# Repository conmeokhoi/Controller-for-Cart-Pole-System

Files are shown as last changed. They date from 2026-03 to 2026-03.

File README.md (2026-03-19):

# 150W Isolated Cart-Pole Control Board (STM32)





## 📌 Project Overview
This project presents the design and implementation of a specialized control board for an Inverted Pendulum on a Cart (Cart-Pole) system. It serves as a benchmark for testing cascaded control strategies in highly non-linear, unstable, and under-actuated environments.

## 🛠 Hardware Architecture

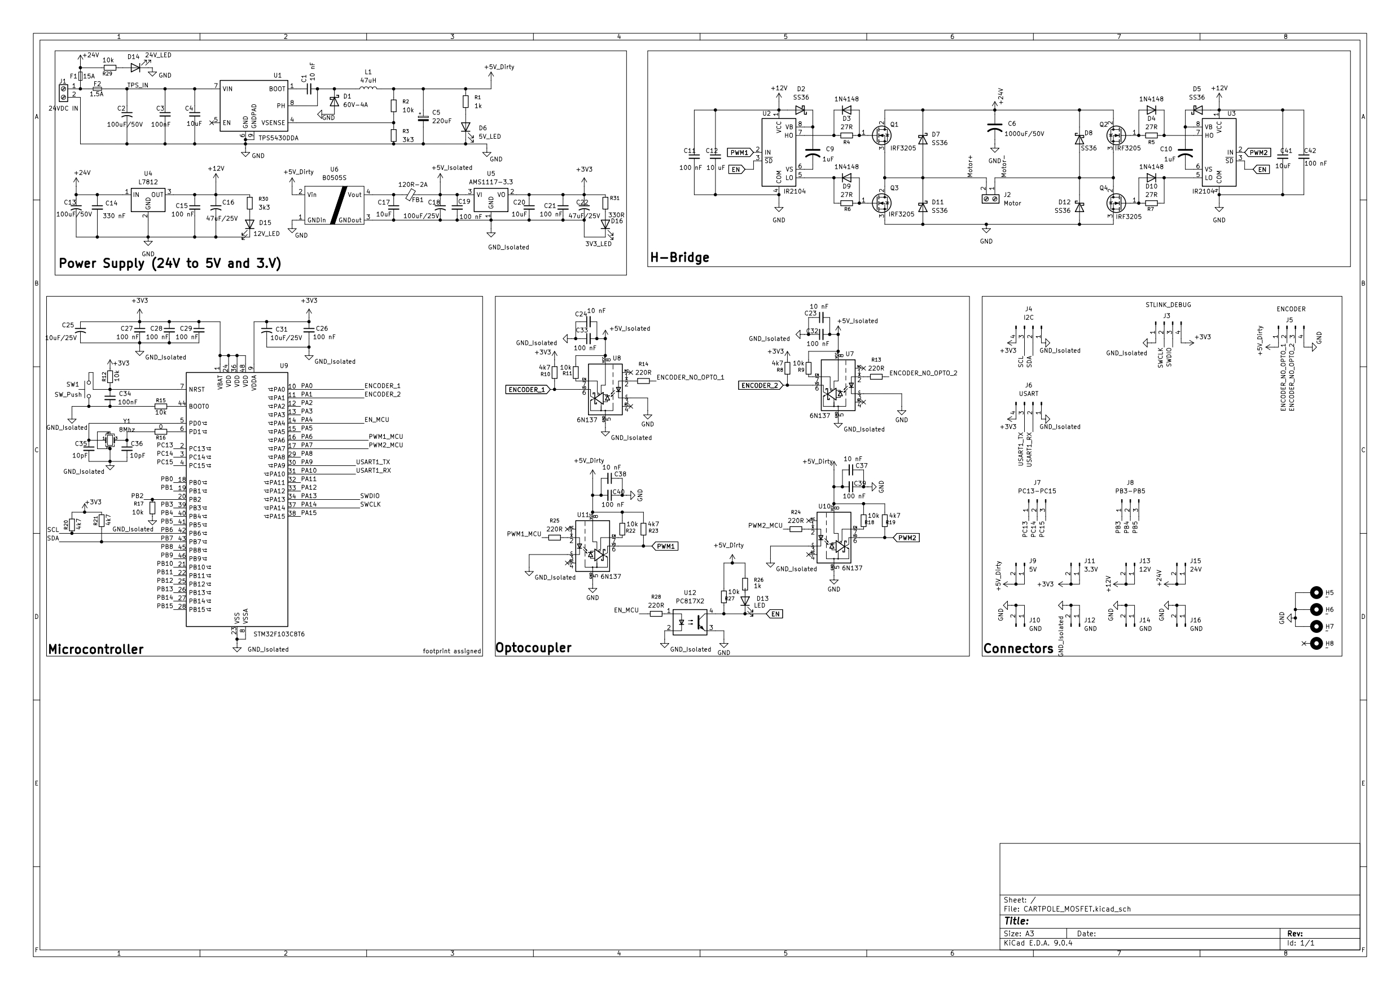
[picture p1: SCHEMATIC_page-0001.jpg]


### 1. Multi-Stage Power Management
The system operates on a primary **24V DC** input with hierarchical regulation to ensure signal stability and efficiency:
* **12V Rail**: Regulated by the **L7812** for MOSFET gate drivers.
* **5V Auxiliary Rail**: Stepped down via a high-efficiency **TPS5430 Buck Converter** (~90% efficiency) to power encoders and sensors.
* **Isolated 3.3V Logic**: Utilizes a **B0505S** isolated DC-DC converter and an **AMS1117-3.3** LDO to shield the MCU from power-stage inductive switching noise.

### 2. Motor Drive Stage (150W H-Bridge)
* **MOSFET Selection**: Features four **IRF3205S** N-channel MOSFETs with an exceptionally low $R_{DS(on)} \approx 8 m\Omega$ to minimize conduction losses.
* **Gate Driving**: Employs **IR2104** drivers with bootstrap circuitry to maintain high-side gate saturation.
* **Safety Logic**: Integrated **520ns hardware dead-time** prevents "shoot-through" short circuits.

### 3. Galvanic Isolation
* **High-Speed Paths**: **6N137 optocouplers** (10Mbps) are dedicated to PWM and Encoder signals to prevent propagation delay in the real-time control loop.
* **Isolation Barrier**: Complete physical partitioning between the Power Zone and Clean Logic Zone via the optocoupler bridge.
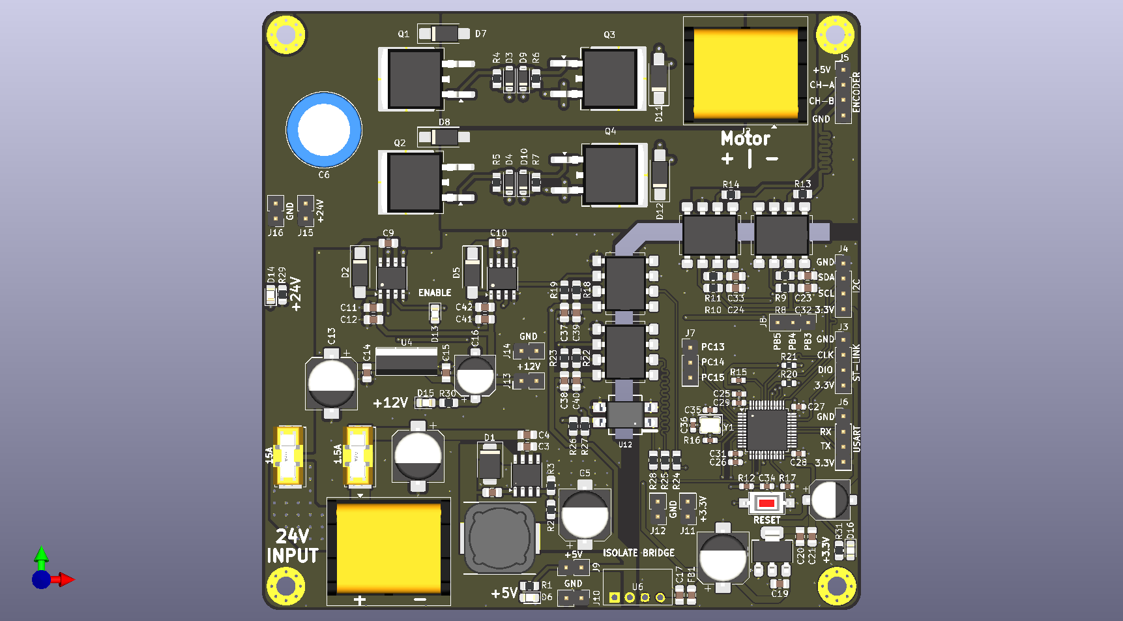
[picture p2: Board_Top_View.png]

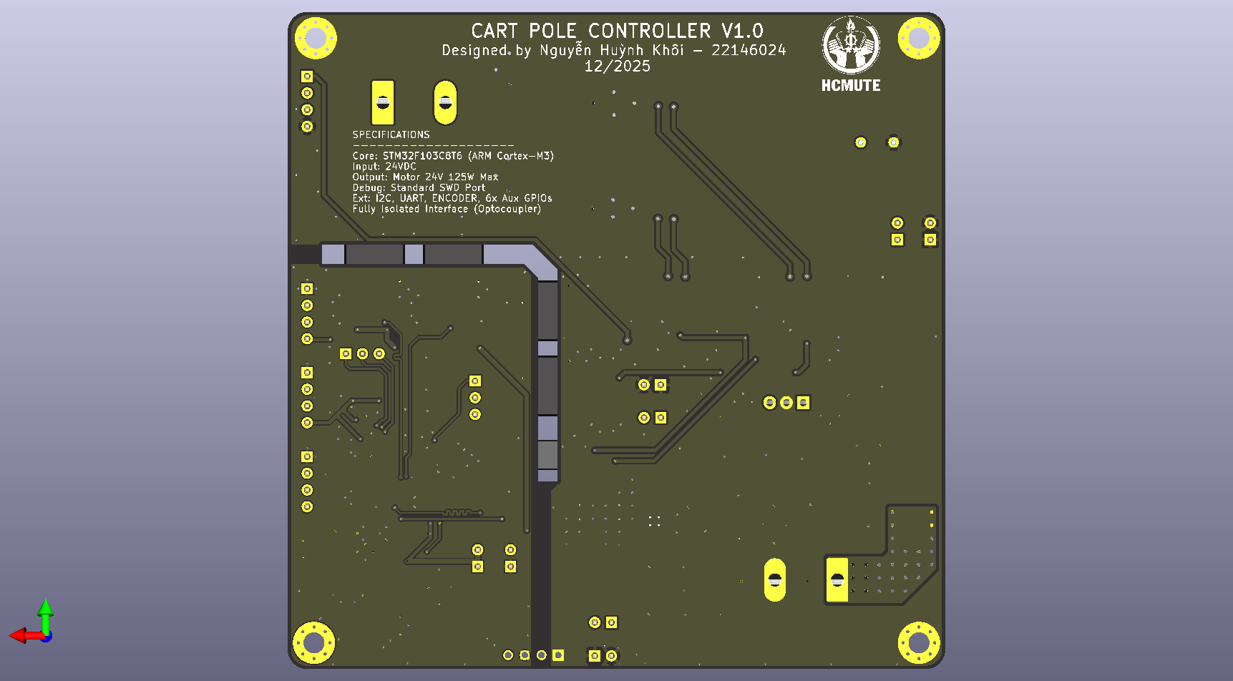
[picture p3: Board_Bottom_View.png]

## 💻 Firmware & Control Logic
Powered by the **STM32F103C8T6** (ARM Cortex-M3) at **72MHz**:
* **Encoder Processing**: Utilizes hardware Timer Encoder Mode for high-resolution quadrature decoding without CPU overhead.
* **PWM Configuration**: Frequency set at **20kHz** to eliminate audible jitter and provide granular torque control:
  $$f_{PWM} = \frac{f_{CLK}}{(PSC+1) \times (ARR+1)} = \frac{72,000,000}{36 \times 100} = 20,000 \text{ Hz}$$
* **Control Algorithm**: Implements a **Cascaded PID** structure where the outer loop manages cart position and the inner loop stabilizes the pendulum angle.

## 🔍 Failure Analysis (Root Cause)
During integration, a hardware breakdown occurred in the H-bridge. Forensic analysis identified a missing connection between the **VS pin** (Pin 6) of the IR2104 drivers and the **source terminals** of the high-side MOSFETs.This led to a "floating gate" state, causing a direct short-circuit from the 24V rail to Ground.

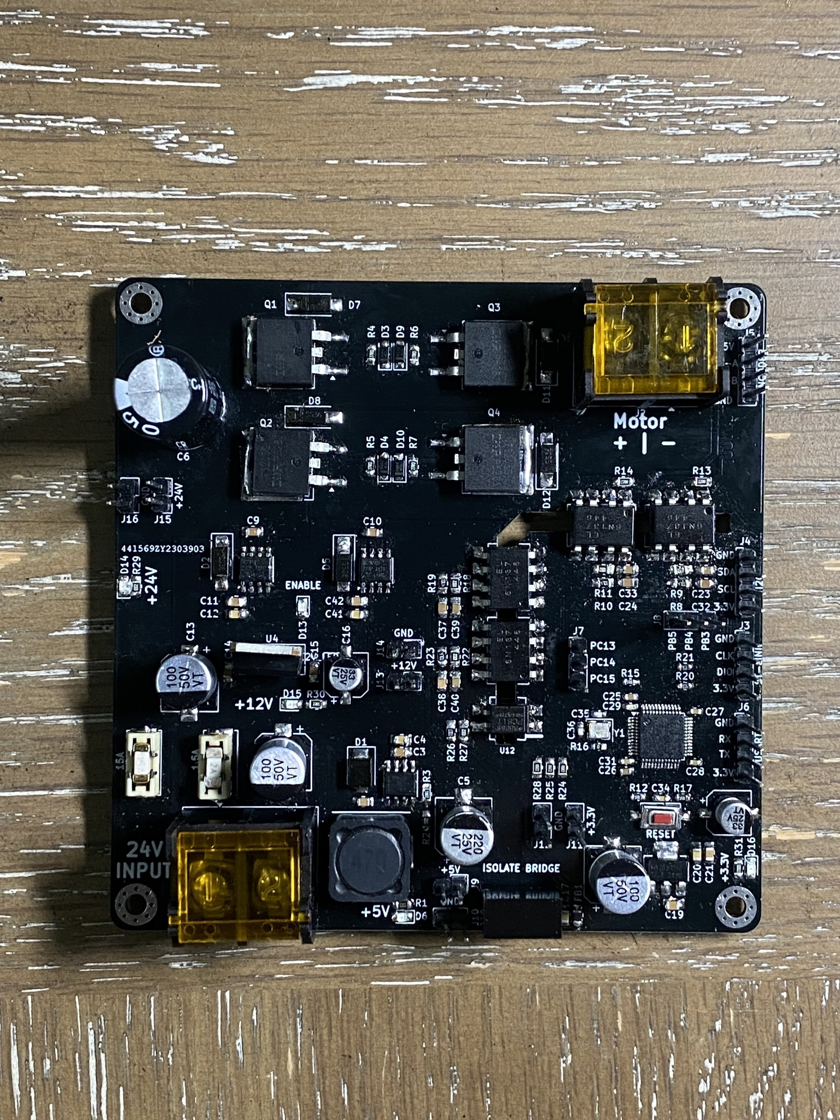
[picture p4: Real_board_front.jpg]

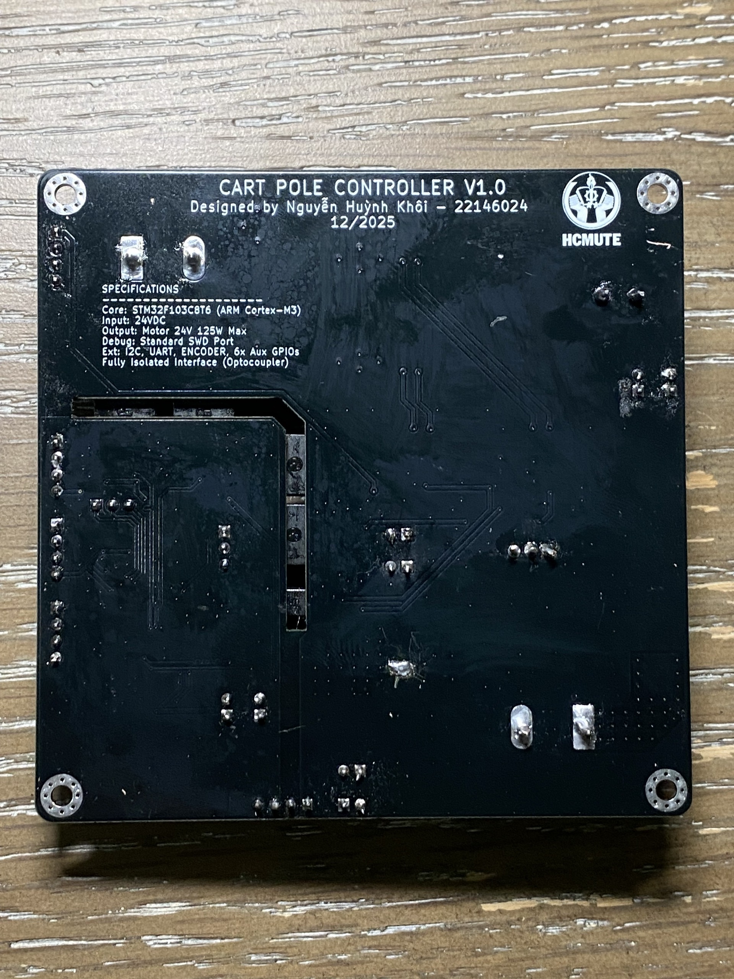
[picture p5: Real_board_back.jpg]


## 🎥 Experimental Validation
The following video demonstrates the individual functional verification of the control board:
* **Hardware Self-Test:** Verification of the 24V, 12V, 5V, and 3.3V power rails.
* **Encoder & Sensor Feedback:** Real-time pulse capturing and gyroscope data retrieval.
* **PWM Output:** Validation of 20kHz complementary signals via oscilloscope.
* **Video Demo:** Cart-Pole Demo (https://youtu.be/A-W4OBMFTu4?si=EoCC8th8CacCnSwT)

---
**Author**: Nguyễn Huỳnh Khôi.  
**Supervised by**: PhD. Võ Lâm Chương.   
**University**: Ho Chi Minh City University of Technology and Engineering (HCMUTE)

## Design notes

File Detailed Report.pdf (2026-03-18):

HO CHI MINH CITY UNIVERSITY OF TECHNOLOGY AND ENGINEERING FACULTY OF ADVANCED EDUCATION

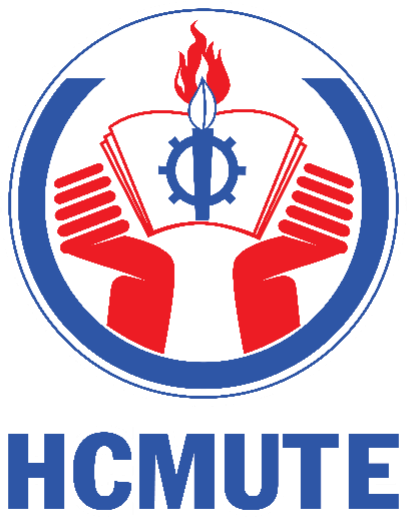
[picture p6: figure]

# DESIGN OF A CONTROL INTERFACE BOARD FOR THE CART-POLE SYSTEM

### Supervisor: PhD. Võ Lâm Chương

### Student: Nguyễn Huỳnh Khôi - ID: 22146024

### Course: Project of Mechatronic System

### Course ID: 251PRME315129E_07FIE

### Semester: I – Academic year: 2025-2026

### Ho Chi Minh City, January, 2026

ACKNOWLDGEMENTS

I would like to extend my deepest and most sincere gratitude to my supervisor,

PhD. Võ Lâm Chương, for his profound guidance, unwavering support, and invaluable

mentorship throughout the entire journey of this project. This research, centered on the

design and implementation of a control interface board for the Cart-Pole system,

presented numerous technical hurdles that would have been insurmountable without his

expertise. While this is not my first experience in designing a Printed Circuit Board, this

project involved the most detailed and complexity layout I have ever attempted. Under

his supervision, I understand the important of the deep research before doing anything

and a lot of precious things. The lessons learned during this process have provided me

with priceless knowledge that will undoubtedly strengthen my professional path and

serve as a cornerstone for my future career as an engineer.

I am also deeply appreciative of the Ho Chi Minh City University of Technology

and Enginnering and the esteemed professors within the Faculty of Mechanical

Engineering. The useful knowledge and robust skills I have acquired through years of

lectures and practical training were essential in allowing me to successfully complete

this Project in Mechatronics. I feel honored to have been part of a faculty that fosters

such a high standard of excellence and innovation.

In the pursuit of engineering, I recognize that mistakes are often unavoidable, yet

they serve as the most profound teachers. Throughout this project, I have exerted my

maximum effort to apply the theoretical concepts I have learned to a physical, working

model. This experience has humbled me and reinforced the realization that knowledge

is infinite. I am fully aware of my current limitations and remain deeply committed to

the philosophy of lifelong learning. Therefore, I sincerely hope to receive constructive

criticism and feedback regarding this work. I welcome every critique as an opportunity

to improve myself, refine my skills, and expand the boundaries of my limited

knowledge. I am truly grateful for the opportunity to have conducted this research, and

I look forward to applying the strengths I have gained here to make meaningful

contributions to the field of engineering in the years to come.

FEEDBACK OF SUPERVISOR

Ho Chi Minh City, January, 2026

Supervisor

TABLE OF CONTENTS

ACKNOWLDGEMENTS | 0
FEEDBACK OF SUPERVISOR | 1
TABLE OF CONTENTS | 2
CHAPTER I: INTRODUCTION | 1
1.1. Background and Motivation | 1
1.2. Objectives of the Thesis | 1
1.3. Scope and Limitation | 2
1.4. Research Methodology | 2
1.5. Thesis Structure | 3
CHAPTER II: THEORETICAL BACKGROUND | 4
2.1. Mathematical Modeling of the Cart-Pole System | 4
2.1.1. System Parameters and Coordinates | 4
2.1.2. Energy Analysis | 5
2.1.3. Euler-Lagrange Equations | 5
2.1.4. Linearization | 6
2.2. PID Control Theory | 6
2.2.1. Individual Control Components | 7
2.2.2. Impact on System Response | 7
2.3. Cascaded PID Control Structure | 8
2.3.1. The Necessity of Dual Control Loops | 8
2.3.2. Operating Principle and Interaction | 8
2.3.3. Sampling Frequency and Stability | 9
2.4. Power Electronics and Motor Driving | 9
2.4.1. H-Bridge and MOSFET Switching | 9
2.4.2. Pulse Width Modulation (PWM) | 10

4.2.3. Timer Interrupt (10ms Periodic Task) | 32
4.3. Controller Programming | 33
CHAPTER V: RESULTS AND EVALUATION | 34
5.1. Hardware Assembly and Power-on Self-Test | 34
5.2. Individual Functional Verification | 34
5.3. Technical Challenges and Failure Analysis | 35
5.3.1. Incident Description | 35
5.3.2. Root Cause Analysis | 36
CHAPTER VI: CONCLUSION | 37
6.1. Conclusion | 37
6.2. Future Work | 37
CITIATION | 38

LIST OF FIGURES

Figure 1.1: Diagram of inverted pendulum on a cart | 4
Figure 2.1: PID Block Diagram | 6
Figure 2.2: Cascade PID System | 8
Figure 2.3: Typical MOSFET H-Bridge configuration | 10
Figure 2.4: PWM & Duty Cycle | 10
Figure 2.5: Linear Voltage Regulator | 11
Figure 2.6: Buck Converter | 12
Figure 2.7: Quadrature Encoder principle | 13
Figure 2.8: Inside of Optocoupler | 13
Figure 3.1: Hardware Architecture for Cart Pole System | 14
Figure 3.2: LM7812 Diagram | 15
Figure 3.3: TPS5430DDAR schematic diagram | 16
Figure 3.4: B0505S Isolation Bridge | 17

Figure 3.5.6: The physical layout of the control board, highlighted the strategic

CHAPTER I: INTRODUCTION

### 1.1. Background and Motivation

The Cart-Pole system, also known as the Inverted Pendulum on a Cart, is one of the

most fundamental and classic problems in control theory and robotics. It serves as a

benchmark for testing various control strategies due to its specific characteristics: it is

highly non-linear, unstable and under-actuated. The challenge of balancing a pole

vertically by moving a cart horizontally mimics real-world applications such as the

stabilization of space booster rockets during takeoff, the balance of humanoid robots,

and the operation of self-balancing personal transporters like Segways. However,

transitioning from theoretical simulations to physical hardware presents several

engineering challenges. Generic development boards (such as STM32 Blue Pill or

Arduino UNO) often lack the specialized interfaces for electrical isolation, power

management, signal integrity and interfacing. Therefore, designing a dedicated control

interface board is essential to ensure system stability, safety, and performance. This

project not only serves as a practical academic exercise but also provides a foundation

for mastering real-time embedded control and high-performance electronic design.

### 1.2. Objectives of the Thesis

The primary objective of this project is to design and manufacture a high-

performance control interface board based on the STM32 microcontroller, focusing on

high-power efficiency and signal integrity. Specifically, the board features a custom

H-Bridge MOSFET driver capable of handling a maximum power output of 150W for

robust DC motor control. The power management system is designed to accept a 24V

DC input and provide multiple regulated voltage levels, including 12V for gate driving

and 5V/3.3V for logic and supply for microcontroller. For feedback accuracy and system

protection, the board integrates high speed – optocoupler isolated for encoder interfaces

and PWM outputs to prevent electromagnetic interference and back-EMF from affecting

the microcontroller. Furthermore, it intergrated standard communication protocols such

as I2C for peripheral sensor and USART for data logging and debugging, while utilizing

high-frequency PWM outputs for smooth and precise motor actuation.

### 1.3. Scope and Limitation

This project focuses on the design and implementation of a custom-built hardware

control system specifically for a linear Cart-Pole system, utilizing the STM32

microcontroller as the primary processing unit. The hardware scope is confined to the

development of a dedicated Printed Circuit Board (PCB) that integrates a MOSFET-

based H-Bridge driver with a power rating of 150W, although the design considerations

allow for higher peaks provided if thermal management is maintained. The system is

designed around a primary 24V DC input, employing a multi-stage regulation strategy

to balance efficiency and signal stability. A linear regulator is utilized to step down 24V

to a 12V rail dedicated to the MOSFET gate drivers; a linear topology is chosen here

due to the low current demand of gate driving, which minimizes circuit complexity. In

contrast, to the voltage differential between the 24V input and the 5V logic level, a high-

efficiency buck converter is implemented. This switching regulator minimizes thermal

dissipation while providing a robust 5V supply for power-intensive peripherals,

including the quadrature encoders and communication interfaces such as I2C and

USART. Finally, the 5V rail is further regulated down to 3.3V to ensure a stable and

low-noise operating voltage for the STM32 microcontroller’s core logic. From a control

perspective, the project implements a Cascaded PID algorithm tailored to the linearized

dynamics of the pendulum near its vertical equilibrium, excluding advanced non-linear

or heuristic control methods.

### 1.4. Research Methodology

This project follows a structured engineering approach consisting of four key

phases: Fristly is Theoretical Modeling by analyzing system dynamics to establish a

linearized mathematical model for PID control design. Next is Hardware Engineering

by designing a high-power PCB that integrates an STM32 Microcontroller, a 150W

MOSFET H-Bridge, and isolated sensor interfaces with a multi-stage power

management system. After that, Software Development by implementing real-time C-

based algorithms on the STM32 platform, leveraging hardware timers for precise PWM

generation and encoder decoding. Finally Experimental Validation by Conducting

physical tests to evaluate system stability and iteratively tuning PID parameters for

optimal balancing performance.

### 1.5. Thesis Structure

- Chapter 1: Introduction - Presents the background, research motivation, technical

objectives, and the overall methodology of the project.

- Chapter 2: Theoretical Background - Discusses the mathematical modeling of the

Cart-Pole system through physics-based equations and explores the theoretical

principles of Cascaded PID control.

- Chapter 3: Hardware Design - Details the design of the control interface board,

including component selection for the 150W MOSFET H-Bridge, the multi-stage power

system, and the PCB layout strategies for signal integrity and thermal management.

- Chapter 4: Software Development - Describes the software architecture on the

STM32 platform, focusing on real-time interrupt handling, hardware-level encoder

decoding, and the implementation of the control algorithms in C language.

- Chapter 5: Results And Evaluation - Details the testing procedures, PID tuning

process, and system performance analysis through real-time data graphs. This chapter

also evaluates the hardware's thermal stability and power handling capabilities under

operational loads.

- Chapter 6: Conclusion – Summarizes the project's outcomes in relation to the

initial objectives, acknowledges technical limitations encountered during development,

and proposes directions for future enhancements and research.

CHAPTER II: THEORETICAL BACKGROUND

### 2.1. Mathematical Modeling of the Cart-Pole System

The foundation of any control system is an accurate mathematical representation

of the physical plant. For the Cart-Pole system, modeling allows us to predict how the

cart's horizontal movement affects the pole's vertical stability. At the undergraduate

level, the Euler-Lagrange method is the most structured approach to deriving these

equations, as it focuses on the energy states of the system rather than complex vector

force diagrams.

### 2.1.1. System Parameters and Coordinates

To begin the analysis, we define the following physical constants and variables:

- M: Mass of the cart.
- m: Mass of the pole.
- l: Length from the pivot to the pole's center of mass.
- I: Moment of inertia of the pole (I =

1
3

ml

2
for a uniform rod).
- g: Acceleration due to gravity (9.81 m/s

2
).
- F: Force applied to the cart (the control input).
- x: Horizontal position of the cart.
- θ: Angle of the pole relative to the vertical (upright) position.

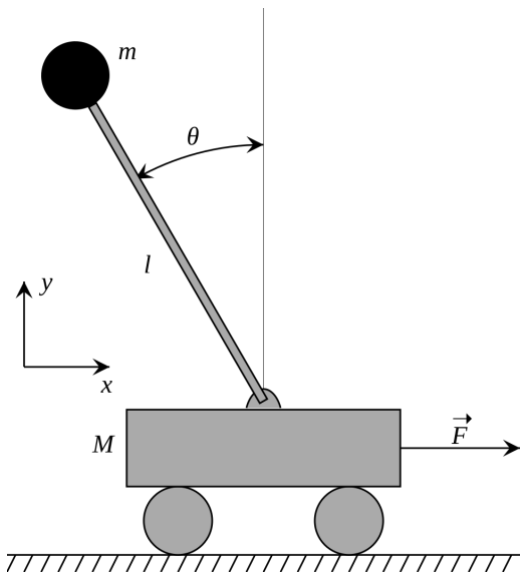
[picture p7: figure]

Figure 1.1: Diagram of inverted pendulum on a cart

The coordinates of the pole's center of mass (xp, yp) are expressed as:

xp = x + lsinθ

yp = lcosθ

### 2.1.2. Energy Analysis

The Lagrangian L is defined as the difference between the Total Kinetic

Energy (K) and the Total Potential Energy (V). Total Kinetic Energy is the energy

consists of the cart's translation and the pole's translation/rotation:

K =

1
2

Mẋ

2 +

1
2

m(xṗ

2 + yṗ

2
) +

1
2

Iθ̇²

By differentiating the coordinates (xp, yp) and substituting them into the

equation, we obtain:

K =

1
2

(M + m)ẋ

2 + mlẋθ̇cosθ +

1
2

(I + ml

2

)θ̇²

Total Potential Energy: Assuming the ground level as the zero-potential

reference:

V = mglcosθ

### 2.1.3. Euler-Lagrange Equations

The equations of motion are derived using the Euler-Lagrange formula for each

generalized coordinate qi

(where q1 = x and q2 = θ):

d
dt (

∂L
∂qi

̇

) −

∂L
∂qi

= Qi

Applying this to the system (where Qx = F and Qθ = 0) results in two coupled,

non-linear differential equations:

(M + m)ẍ+ mlθ̈cosθ − mlθ̇² sinθ = F

(I + ml

2

)θ̈+ mlẍcosθ − mglsinθ = 0

### 2.1.4. Linearization

Because standard PID controllers are linear, we must linearize the system around

the unstable equilibrium point (upright position, θ ≈ 0). For small angles, we can

assume:

- sinθ ≈ 0
- cosθ ≈ 1
- θ̇² ≈ 0 (negligible higher-order terms)

The linearized equations of motion become:

(M + m)ẍ+ mlθ̈= F

(I + ml

2

)θ̈+ mlẍ= mglθ

These equations represent the "transfer function" that controller board will eventually control through the PID algorithm.

### 2.2. PID Control Theory

The PID controller operates by continuously calculating an "error" value as the

difference between a desired setpoint and a measured process variable. For the

Cart-Pole system, this error represents how far the pole is from the vertical position or

how far the cart is from its target on the track.

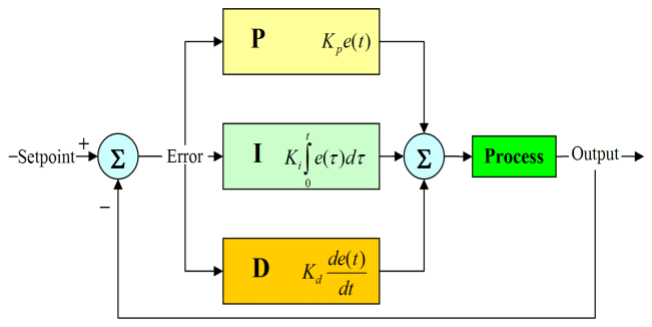
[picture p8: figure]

Figure 2.1: PID Block Diagram

### 2.2.1. Individual Control Components

The standard continuous-time PID control law is defined by the following

equation:

u(t) = Kpe(t) + Ki ∫ e(τ)dτ

t

0

+ Kd

de(t)
dt

Where:

- u(t): The control output
- e(t): The error signal, calculated as Setpoint – Measured Value
- Kp (Proportional Gain): Provides a control output that is directly proportional to

the current error. In the Cart-Pole system, a higher Kp makes the motor react more

aggressively as the pole tilts. However, if Kp is too high, the system will

overshoot the setpoint and oscillate.

- Ki
(Integral Gain): Accounts for the accumulation of past errors. If the error

persists over time, the integral term increases the control effort to eliminate the

offset.

- Kd (Derivative Gain): Estimates the future trend of the error based on its current

rate of change. It acts as a "damper" or a brake. If the pole is falling rapidly, the

derivative term anticipates the impact and applies a counter-force to slow down

the motion before it reaches the setpoint. This is critical for the Cart-Pole system

to prevent the violent oscillations caused by the Kp and Ki
terms.

### 2.2.2. Impact on System Response

When tuning term Kp,Ki or Kd the interaction between these terms determines

the stability of the cart. The following table summarizes the general effects of increasing

each parameter on the system's step response:

Parameter | Rise Time | Overshoot | Settling Time | Steady-State Error
Increasing Kp | Decrease | Increase | Small Change | Decrease
Increasing Ki | Decrease | Increase | Increase | Eliminate
Increasing Kd | Small Change | Decrease | Decrease | No Change

### 2.3. Cascaded PID Control Structure

The Cart-Pole system is a classic example of an under-actuated system, meaning

it possesses more degrees of freedom (horizontal position x and pole angle θ) than

available control inputs (a single DC motor force F). A standard single-loop PID

controller is insufficient for this task because stabilizing the angle often causes the cart

to drift uncontrollably, eventually hitting the track limits. To resolve this, a Cascaded

PID Control architecture is employed.

### 2.3.1. The Necessity of Dual Control Loops

In a cascaded configuration, the control task is divided into two distinct

objectives that operate at different priorities and time scales are Inner Loop (Angle

Control): This is the high-speed loop responsible for the primary task of balancing the

pole vertically. Since the pole is inherently unstable, this loop must have a high sampling

frequency to react to the slightest tilt. Next is Outer Loop (Position Control): This loop

manages the cart's horizontal position on the track. Its role is to ensure the cart stays at

the center or moves to a specific setpoint, preventing it from running off the track

boundaries.

### 2.3.2. Operating Principle and Interaction

The fundamental logic of cascade control is that the Outer Loop provides the

setpoint for the Inner Loop. Instead of the motor acting directly on the cart's position,

the position controller tells the angle controller how much the pole should "lean" to

achieve the desired movement. Position Regulation (Outer Loop): The controller

calculates the error between the desired cart position (xref) and the actual position (x).

Figure 2.2: Cascade PID System

The output of this loop is not a voltage, but a target tilt angle (θtarget). To move the cart

to the right, the controller commands the pole to tilt slightly to the right. Angle

Stabilization (Inner Loop): The inner loop takes the θtarget from the outer loop and

compares it with the current pole angle (θ). It then calculates the necessary PWM duty

cycle for the motor to achieve that tilt. By trying to "catch" the falling pole, the motor

effectively moves the cart in the direction of the tilt.

### 2.3.3. Sampling Frequency and Stability

For the cascaded system to remain stable, the Inner Loop must be significantly

faster than the Outer Loop (typically 5 to 10 times faster) cause if the angle loop is too

slow, the pole will fall before the position loop can even react. In this project, the

STM32's hardware timers are configured to execute the Inner Loop at a high frequency

(200Hz - 500Hz), while the Outer Loop can operate at a lower frequency (50Hz -

100Hz). This separation ensures that the stabilization of the pole is always prioritized

over the positioning of the cart.

### 2.4. Power Electronics and Motor Driving

### 2.4.1. H-Bridge and MOSFET Switching

In the Cart-Pole system’s power stage, the MOSFET (Metal-Oxide -

Semiconductor Field - Effect Transistor) functions as a high-speed electronic switch that

alternates between cut-off and saturation regions to regulate power. When the Gate-

Source voltage (VGS) is significantly higher than the threshold voltage, the device enters

the saturation region, exhibiting a minimal on-state resistance (RDS(On)) which allows

high current to pass from Drain to Source with very low thermal dissipation.

These MOSFETs are organized into an H-Bridge topology, consisting of four

switches that allow the DC motor to be driven in two directions by alternating the current

flow path. Specifically, turning on diagonal pairs allows for forward or reverse torque,

which is essential for the rapid corrections required to balance the pendulum.

### 2.4.2. Pulse Width Modulation (PWM)

Pulse Width Modulation is a fundamental technique used to regulate the average

voltage delivered to an electrical load by rapidly switching the power supply on and off.

In the context of motor control, the speed and torque are determined by the duty cycle,

which is the ratio of the "on" duration to the total period of one switching cycle. The

average voltage (Vavg) applied to the motor is calculated as the product of the supply

voltage (Vcc) and the duty cycle (D), expressed by the formula Vavg = D × Vcc.

Figure 2.3: Typical MOSFET H-Bridge configuration

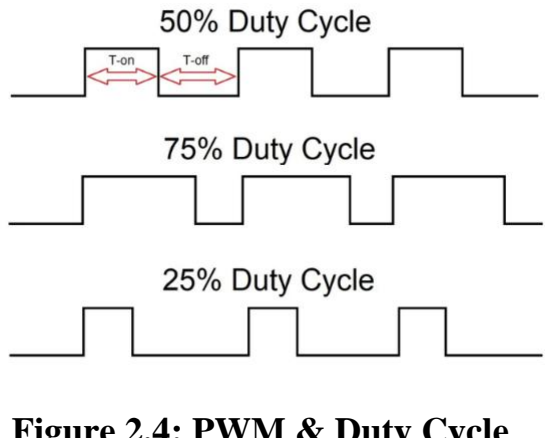
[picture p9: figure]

Figure 2.4: PWM & Duty Cycle

This method is highly efficient compared to linear voltage regulation because the

switching elements ideally dissipate zero power when they are either fully on or fully

off. For a dynamic system such as an inverted pendulum, a sufficiently high PWM

frequency is essential to ensure that the current through the motor remains continuous

and smooth, leveraging the motor's internal inductance to filter the high-frequency

pulses. Maintaining a consistent switching frequency helps prevent mechanical jitter and

audible noise while providing the granular control necessary for the precise,

millisecond-level adjustments required to maintain the system's equilibrium.

### 2.4.3. DC-DC Conversion Principles

In electronic system design, DC-DC conversion is the process of transforming a

source of direct current from one voltage level to another to meet the specific

requirements of various circuit components. Linear regulation operates by using a pass

element—typically a transistor—to drop the excess voltage, where the dissipated power

is the product of the current and the voltage difference between the input and output

(Ploss = (Vin − Vout) × Iload). While linear regulators provide low-noise outputs and

design simplicity, their efficiency decreases significantly as the voltage gap increases,

leading to high thermal stress and the need for large heatsinks.

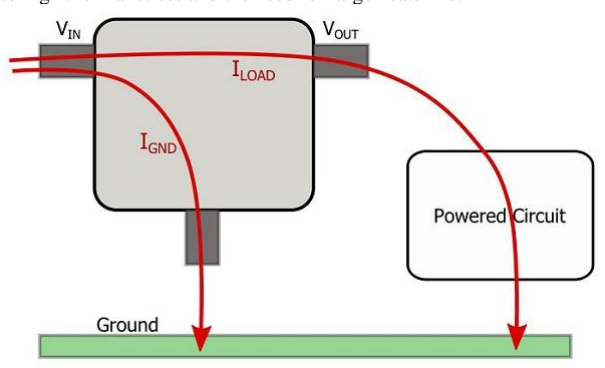
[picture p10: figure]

In contrast, a Buck converter, or step-down switching regulator, achieves much

higher efficiency by using a switching element, an inductor, and a capacitor to store and

release energy. By varying the duty cycle of the switch, the Buck converter delivers only

the necessary energy to the load, theoretically eliminating the power loss associated with

Figure 2.5: Linear Voltage Regulator dropping voltage through resistance. This switching topology is particularly essential

for bridging large voltage gaps, such as reducing a 24V supply to a 5V logic level, where

a linear regulator would waste over 75% of the input power as heat.

Consequently, a hybrid approach using switching regulators for high-current,

large-drop stages and linear regulators for low-current, noise-sensitive stages is often

employed to optimize the system's overall power efficiency and thermal stability.

### 2.5. Sensing and Signal Conditioning

### 2.5.1. Quadrature Encoder Principles

A quadrature encoder is an incremental rotary sensor that provides high-

resolution feedback on position and velocity by generating two square wave signals,

Phase A and Phase B, which are electrically offset by 90 degrees. This phase shift,

known as quadrature, allows the STM32 microcontroller to determine the direction of

rotation by detecting which signal leads the other; for instance, Phase A leading Phase

B indicates clockwise rotation, while Phase B leading Phase A indicates counter-

clockwise movement. By utilizing hardware-level timer peripherals in Encoder Mode,

the system can count every rising and falling edge of both channels, effectively

quadrupling the pulses per revolution (4x encoding) to achieve the granular precision

required for balancing the pendulum.

Figure 2.6: Buck Converter

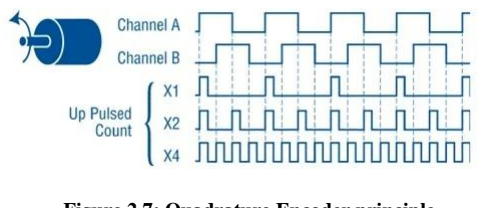
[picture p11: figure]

### 2.5.2. Galvanic Isolation and Signal Conditioning

Galvanic isolation is a design principle used to separate functional sections of

electrical systems to prevent direct current conduction while still allowing for the

exchange of signals or power. In high-power control boards, optocouplers are the

primary components used to achieve this by converting electrical signals into light via

an internal LED and back into electricity using a phototransistor.

This light-based transmission creates an insulation barrier that protects the

sensitive 3.3V STM32 logic circuitry from high-voltage spikes, electromagnetic

interference (EMI), and ground loops generated by the 24V motor power stage.

Furthermore, signal conditioning circuits, such as RC low-pass filters and pull-up

resistors, are integrated to debounce encoder signals and ensure that the digital inputs

received by the MCU are clean and free from high-frequency switching noise, which is

critical for the stability of the real-time PID control algorithm.

Figure 2.7: Quadrature Encoder principle

Figure 2.8: Inside of Optocoupler

CHAPTER III: HARDWARE DESIGN

### 3.1. System Architecture

The overall hardware architecture and the interconnections between the control,

power, and sensing modules are illustrated in Figure 3.1 below.

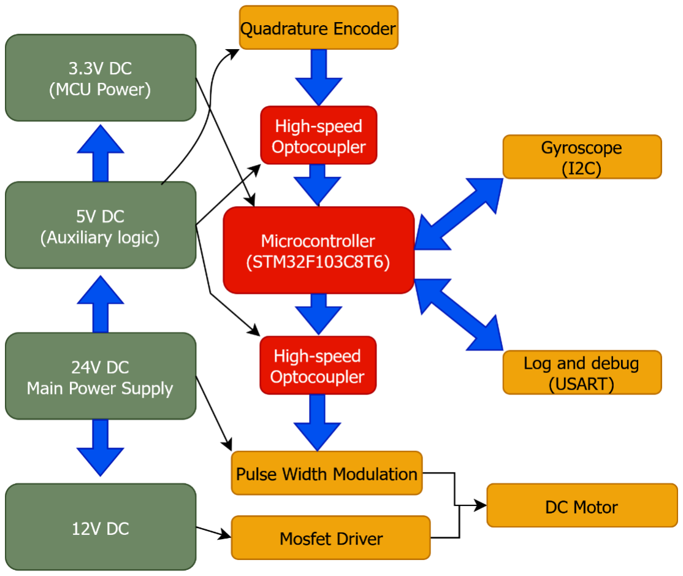
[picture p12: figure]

The system is designed as a multi-stage control and power distribution network

centered around the STM32F103C8T6 microcontroller. The power sub-system

originates from a 24V DC Main Power Supply, which is regulated down to a 12V DC

rail for the Mosfet Driver, a 5V DC rail for auxiliary logic, and a stabilized 3.3V DC rail

dedicated to the MCU’s core operations. To ensure high signal integrity and protect the

sensitive 3.3V logic from high-voltage transients, the architecture incorporates high-

speed optocouplers that provide galvanic isolation for both the incoming feedback from

the Quadrature Encoder and the outgoing Pulse Width Modulation (PWM) control

signals. In addition to encoder feedback, the system integrates a Gyroscope via the I2C

protocol for orientation sensing and utilizes a USART interface for real-time logging

and debugging purposes. The final actuation stage involves the isolated PWM signals

Figure 3.1: Hardware Architecture for Cart Pole System driving a Mosfet Driver—powered by the 12V rail—which manages the power delivery

to the DC Motor, allowing for the rapid and precise torque adjustments necessary to

stabilize the cart-pole system.

### 3.2. Power Management Unit

The power management system is a cornerstone of the control board, designed to

ensure that each functional block receives a stable and noise-free voltage. Given the

high-power nature of the 150W H-Bridge, the strategy focuses on hierarchical regulation

and galvanic isolation to protect sensitive logic from inductive switching noise.

3.2.1. 12V DC for Gate Drivers (L7812)

The primary 24VDC input is regulated down to a 12VDC rail specifically for the

MOSFET gate drivers using the L7812 linear regulator. The choice of a linear regulator

for this stage is driven by its simplicity and the relatively low current requirement of the

IR2104 drivers. A 12V supply is critical because it ensures the MOSFETs operate in the

full saturation region, minimizing on-state resistance (RDS(on)) and preventing

overheating.

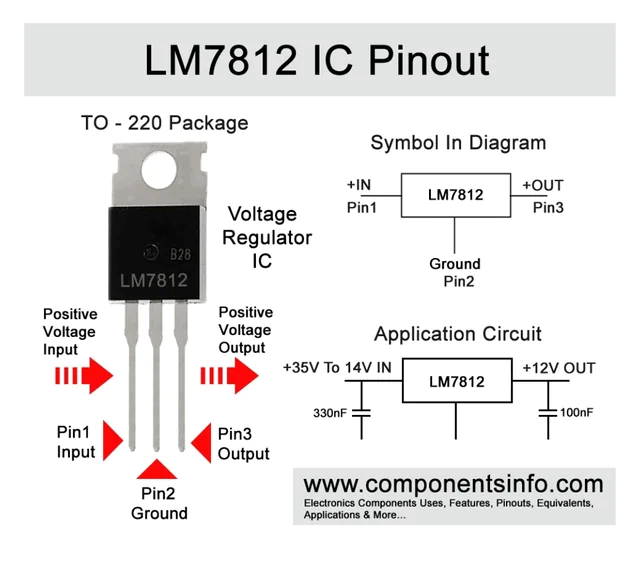
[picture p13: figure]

Figure 3.2: LM7812 Diagram

Although linear regulators are less efficient than switching converters, a linear

regulator was selected for the 12V rail due to the minimal current requirements of the

gate drivers. Since the drivers consume only a few milliamperes, the resulting thermal

dissipation is negligible, making this approach more cost-effective and simpler to

implement than a buck converter.

### 3.2.2. High-Efficiency 5V Auxiliary Rail (TPS5430DDAR)

To power the auxiliary logic and sensors, the 24VDC source is stepped down to

5VDC using the TPS5430DDAR Buck converter. A switching regulator was chosen for

this stage over a linear alternative due to the significant voltage drop (24V to 5V). Using

a linear regulator would result in a theoretical efficiency of only 20%, wasting the

remaining 80% as heat. The TPS5430DDAR, operating at a high switching frequency,

offers up to 90% efficiency and can provide up to 3A of current.

This ensures that the system can power multiple sensors and LEDs without the

need for massive heatsinks, maintaining a compact PCB footprint and high thermal

reliability.

### 3.2.3. Isolated 3.3V Logic Supply (B0505S and AMS1117)

The most sensitive part of the system, the STM32F103C8T6 microcontroller,

requires an isolated and precision power source. This is achieved by passing the 5V

auxiliary rail through a B0505S isolated DC-DC converter. The primary reason for this

choice is to create "Galvanic Isolation" between the noisy power ground (used by the

Figure 3.3: TPS5430DDAR schematic diagram motor) and the clean logic ground. This isolation prevents ground loops and inductive

spikes from the H-Bridge from resetting or damaging the MCU.

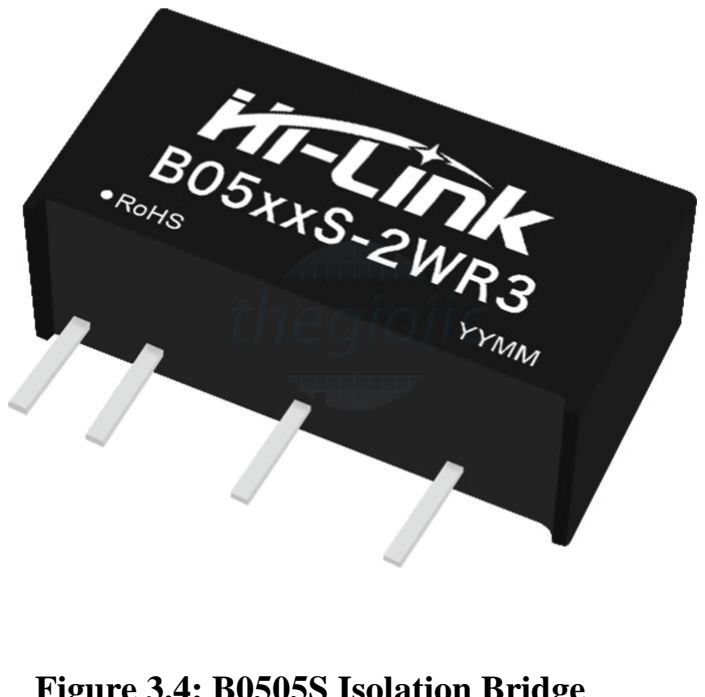
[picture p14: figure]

The isolated 5V output is then fed into an AMS1117-3.3 Low-Dropout (LDO)

regulator. The AMS1117 was selected for its ability to provide a very stable 3.3VDC

output with minimal voltage ripple, which is crucial for the accuracy of the MCU’s

internal ADC and the stability of the real-time control algorithm.

Figure 3.4: B0505S Isolation Bridge

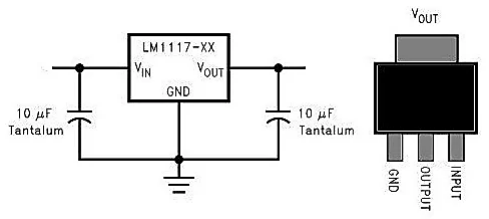
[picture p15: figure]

Figure 3.5: AMS1117-3.3V

### 3.3. Motor Drive Stage

The motor drive stage is the power-delivering heart of the system, responsible

for converting low-level PWM signals from the STM32 into high-current drive signals

for the 24V DC motor. This stage is designed to handle peak power loads of up to 150W

while maintaining high switching efficiency and electrical robustness.

### 3.3.1. H-Bridge Topology and MOSFET Selection

The system utilizes a full H-bridge configuration consisting of four IRF3205S N-

channel MOSFETs. These specific transistors were selected for their exceptionally low

on-resistance (RDS(on) of approximately 8 mΩ), which is critical for minimizing

conduction losses and heat dissipation when driving currents up to 8-10A. By using N-

channel MOSFETs for both the high-side and low-side switches, the design achieves

better performance and cost-efficiency compared to P-channel alternatives, provided

that a suitable gate driver is used to manage the high-side gate voltage.

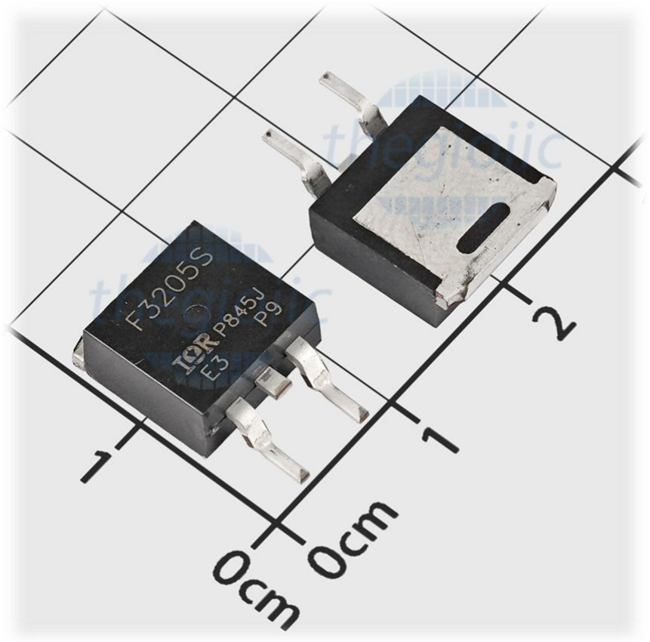
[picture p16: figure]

Figure 3.6: IRF3205S N-channel MOSFET

### 3.3.2. IR2104 Gate Driving and Bootstrap Mechanism

To interface the 3.3V logic of the STM32 with the 24V power stage, two IR2104

Half-Bridge Driver ICs are utilized to perform level-shifting, current amplification, and

high-side gate driving. The IR2104 provides the necessary peak current to rapidly charge

the non-linear gate capacitance of the IRF3205S MOSFETs, ensuring clean and efficient

transitions. A vital safety feature of this driver is the integrated dead-time logic, which

introduces a 520ns delay to prevent "shoot-through"—a condition where both the high-

side and low-side MOSFETs are active simultaneously, causing a catastrophic short

circuit. Because the system uses N-channel MOSFETs for the high-side, the gate voltage

must be maintained at approximately 12V higher than the source voltage (Vsource +

12V) to remain fully saturated. This is achieved through a bootstrap circuit consisting

of a high-speed diode and a reservoir capacitor. When the low-side MOSFET is active,

the capacitor charges to 12V from the L7812 rail, when the high-side switch is required

to turn on, the capacitor "floats" to provide the elevated potential needed to drive the

high-side gate, eliminating the requirement for an additional isolated power supply for

the high-side logic.

### 3.4. Microcontroller and Sensing Interfaces

The control intelligence and feedback acquisition of the Cart-Pole system are

centered around the STM32 microcontroller, supported by an isolated sensing network

to maintain high-speed real-time performance.

Figure 3.7: IR2104 MOSFET Driver

### 3.4.1. Central Microcontroller Unit (STM32F103C8T6)

The STM32F103C8T6, based on the ARM Cortex-M3 core, serves as the

system's "brain" due to its ability to operate at a 72MHz clock frequency, which is more

than sufficient for executing complex cascaded PID algorithms within millisecond

intervals. Key peripherals utilized in this design include Advanced-control Timers

(TIM1) for generating high-frequency complementary PWM signals, General-purpose

Timers configured in hardware Encoder Mode to track position without CPU overhead,

and I2C/USART interfaces for sensor communication and debugging. The 3.3V logic

level provides a low-power footprint while maintaining compatibility with modern

digital sensors.

### 3.4.2. Signal Isolation and Conditioning

Galvanic isolation is implemented to decouple the sensitive 3.3V STM32 logic

from the high-power 24V motor stage, ensuring system stability and protecting the MCU

from electromagnetic interference (EMI) and inductive voltage spikes. For time-critical

data paths, specifically the high-frequency PWM output signals sent to the gate drivers

and the rapid pulse input signals from the encoders, the system utilizes 6N137 high-

speed optocouplers. The 6N137 is capable of handling data rates up to 10 Mbps, which

is essential to prevent propagation delays or signal distortion that would otherwise

introduce phase lag and instability into the real-time cascaded PID control loop.

Figure 3.7: STM32F103C8T6 Microcontroller

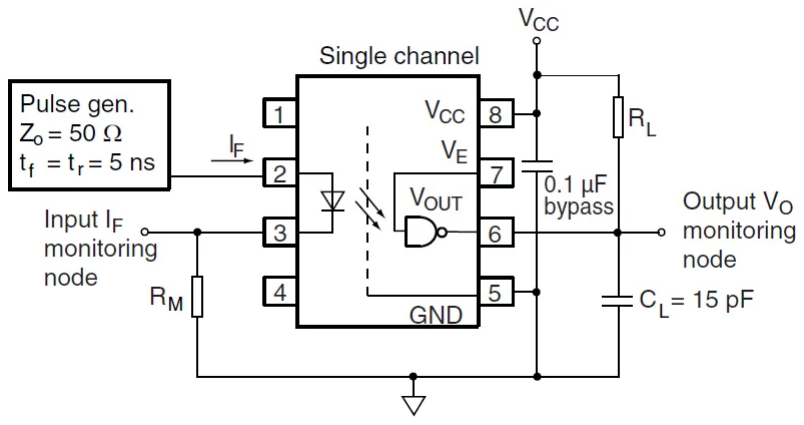
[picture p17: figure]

In contrast, for general logic signals and non-time-sensitive digital I/O, the

PC817 standard optocoupler is employed. The PC817 provides a reliable and cost-

effective isolation barrier for static or low-frequency signals where high-speed

switching is not required. By segregating the signal paths in this manner, the control

board achieves a robust balance between high-speed performance and economic design,

effectively eliminating ground loops and safeguarding the STM32F103C8T6 from the

harsh electrical environment of the 150W power stage.

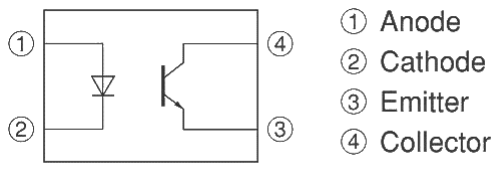
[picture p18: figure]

3.5: Schematic Design & PCB Prototype

This section details the transition from theoretical component selection to the

physical implementation of the control board. The design focuses on integrating the

diverse voltage rails, high-speed signal paths, and high-power actuation components

into a reliable and compact system.

Figure 3.8: 6N137 High Speed Optocoupler

Figure 3.9: PC817 Optocoupler

### 3.5.1. Schematic Design

By | integrating | the | previously | selected | components—including | the

STM32F103C8T6 microcontroller, the TPS5430 buck converter for high-efficiency

power, and the IR2104 gate drivers—the schematic ensures that all modules

communicate effectively while maintaining strict electrical boundaries. A primary focus

of the layout is the implementation of the galvanic isolation strategy, where 6N137 and

PC817 optocouplers are placed to bridge the logic and power domains without direct

electrical contact. Following the design specifications and the hierarchical power

strategy discussed in earlier sections, the complete schematic diagram is presented

below:

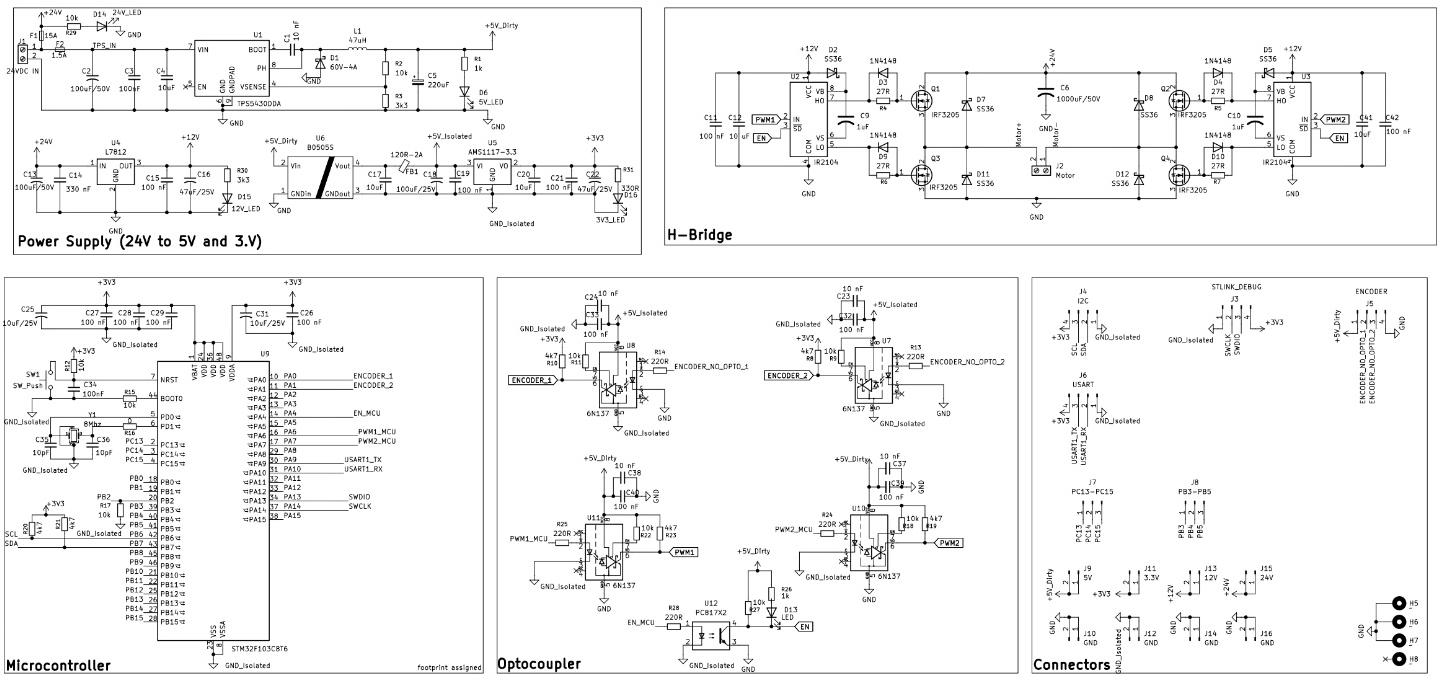
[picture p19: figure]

### 3.5.1.1. Power Supply Circuit

The power supply circuit is responsible for converting the 24VDC input into the

various stable voltage rails required by the system's components. At the primary input,

a fuse is integrated into the circuit to provide essential short-circuit protection,

safeguarding the entire board and the 24V power source from catastrophic failure in the

event of a component breakdown or accidental wiring error.

Figure 3.5: Full System Schematic

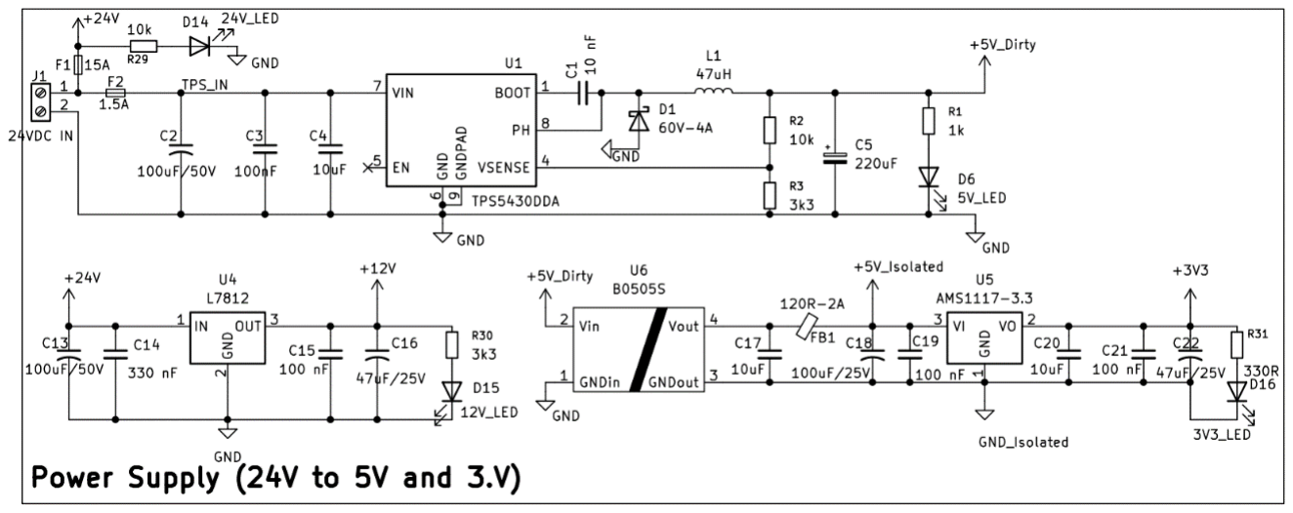
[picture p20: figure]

As shown in the schematic detail, the TPS5430 buck converter follows the

protection stage, utilizing an inductor and high-quality filtering capacitors to deliver a

high-efficiency 5V auxiliary rail. The L7812 linear regulator is implemented with

specific decoupling capacitors to provide a steady 12V supply for the gate drivers.

Finally, the combination of the B0505S isolated DC-DC converter and the AMS1117

regulator establishes a completely isolated 3.3V domain, ensuring the logic circuitry is

shielded from the power stage's electrical noise.

### 3.5.1.2. Microcontroller and Signal Conditioning

The central control unit of the system is the STM32F103C8T6 microcontroller,

which is surrounded by essential signal conditioning and support circuitry to ensure

high-speed processing stability and signal integrity. As illustrated in the schematic, the

design focuses on four critical areas: power stability, timing accuracy, communication

reliability, and peripheral mapping. Power Stability and Noise Filtering To maintain a

noise-free environment for the 3.3V logic core, a comprehensive decoupling capacitor

network is implemented. The VDD and VDDA pins are equipped with 100nF ceramic

capacitors (C27, C28, C29, and C26) placed in close proximity to each pin to filter high-

frequency switching noise. Additionally, 10uF bulk capacitors (C25 and C31) are

utilized to act as energy reservoirs, compensating for low-frequency voltage

fluctuations. All logic components are referenced to a dedicated GND_Isolated plane,

ensuring that the ground loops from the high-power motor stage do not interfere with

the MCU’s operations.

Figure 3.5.1: Power Supply Diagram

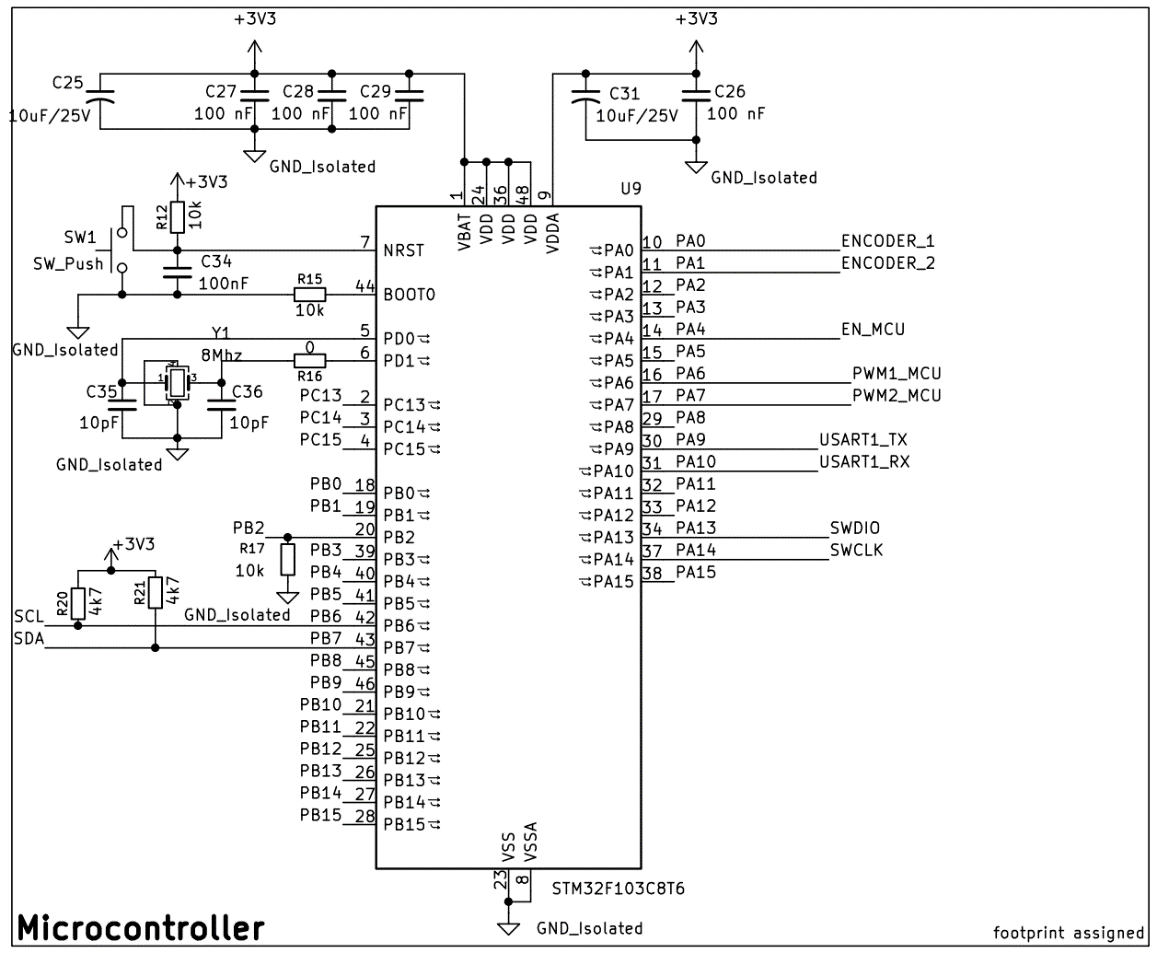
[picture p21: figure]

Clock and Reset Circuitry For the precise timing required by the cascaded PID

algorithm and encoder pulse counting, the system utilizes an external 8MHz crystal

oscillator (Y1) connected to pins PD0 and PD1. This external source provides superior

frequency stability compared to internal RC oscillators. Two 10pF load capacitors (C35

and C36) are paired with the crystal to ensure reliable oscillation startup. The system

reset (NRST) is managed by an RC network consisting of a 10kΩ resistor (R12) and a

100nF capacitor (C34), which provides a clean power-on reset signal and allows for

manual restarts via the button. Communication and Interface Configuration The sensing

and debugging interfaces are configured to maximize the MCU's hardware peripheral

efficiency as I2C Interface: The PB6 (SCL) and PB7 (SDA) pins are dedicated to the

gyroscope. These lines are pulled high by 4.7kΩ resistors (R20 and R21), which are

necessary to maintain the signal integrity of the I2C open-drain architecture. Encoder

Inputs: PA0 and PA1 are mapped to the hardware timer’s encoder mode for high-

resolution position tracking. PWM Outputs: PA6 and PA7 provide the control signals

for the isolated gate drivers. System Enable: PA4 is used as a master enable signal to

engage or disengage the motor drive stage. Debug and Programming: The USART1

Figure 3.5.2: Microcontroller Diagram

(PA9 and PA10) pins are reserved for real-time data logging, while PA13 (SWDIO) and

PA14 (SWCLK) facilitate Serial Wire Debugging (SWD) for firmware development.

### 3.5.1.3. H-Bridge Stage

The power stage is implemented as a full H-bridge configuration to provide

bidirectional torque and PWM speed control for the 24V DC motor. This stage is

optimized for 150W operation through the following design choices:

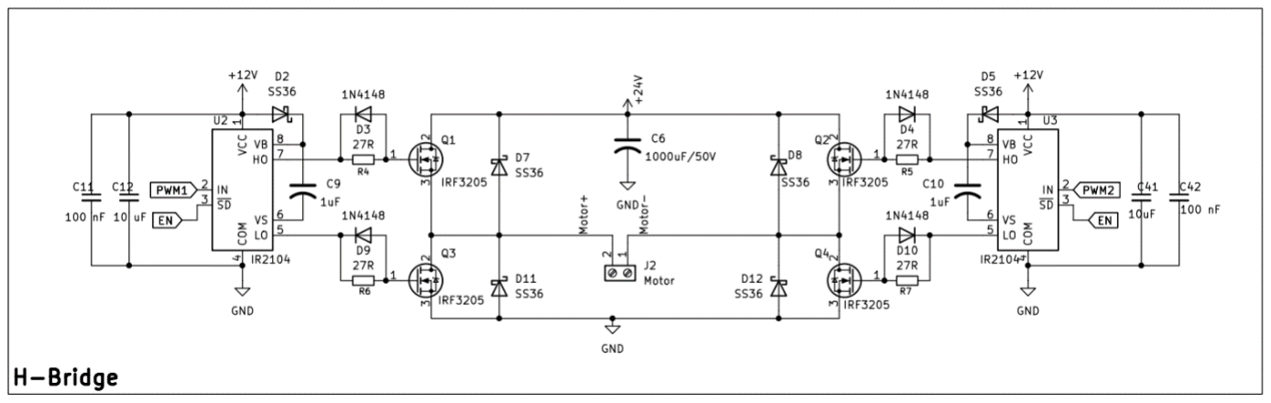
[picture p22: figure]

Four IRF3205 MOSFETs are utilized, chosen for their exceptionally low

RDS(on)
to minimize conduction losses and thermal dissipation during high-current

demands. Two IR2104 drivers (U2, U3) manage the MOSFETs. A bootstrap

mechanism, consisting of SS36 Schottky diodes (D2, D5) and 1uF capacitors (C9, C10),

is employed to provide the floating voltage required to drive the high-side N-channel

MOSFETs into full saturation. each MOSFET gate is interfaced with a 27 Ω resistor in

parallel with a 1N4148 diode. This ensures controlled turn-on while providing a low-

impedance path for rapid gate discharge, effectively preventing shoot-through. A

1000uF/50V electrolytic capacitor (C6) acts as a bulk reservoir to stabilize the supply

rail, while four SS36 freewheeling diodes (D7, D8, D11, D12) suppress inductive back-

EMF spikes generated by the motor during high-frequency switching.

### 3.5.1.4. Optocoupler and Connector Interface

This section details the physical implementation of the signal isolation and

external connection points required for a modular and protected control system.

Figure 3.5.3: MOSFET H – Bridge with IR2104 MOSFET Driver Diagram

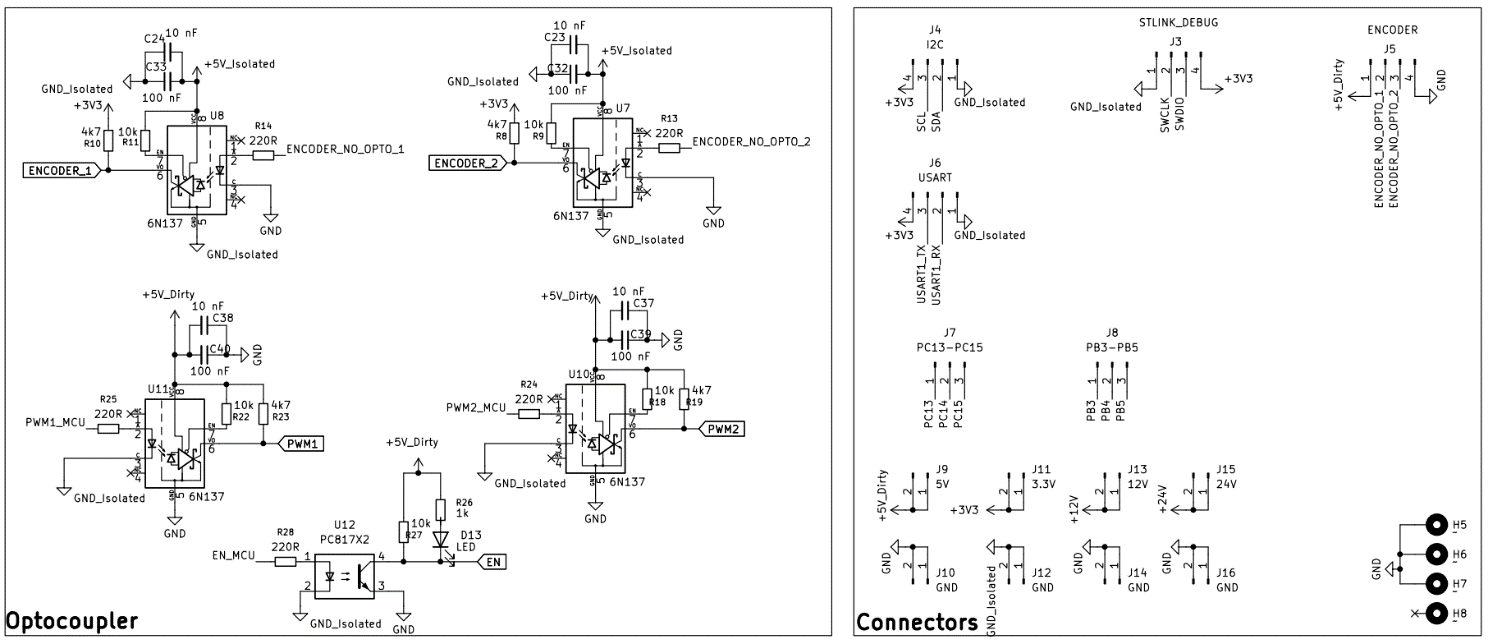
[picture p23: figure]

Optocoupler Isolation Circuitry As previously established in the architecture, the

board utilizes two types of optoisolators to bridge the logic and power domains. The

6N137 high-speed optocouplers (U7, U8, U10, and U11) are dedicated to the PWM and

Encoder signals. These paths include 220 Ω current-limiting resistors (R25, R24) and

pull-up networks (R10, R11, etc.) to ensure sharp signal transitions at high frequencies.

For the master Enable signal, a PC817 optocoupler (U12) is used. This sub-circuit

includes a status LED (D13) to provide a visual indication when the motor drive stage

is energized. Each optocoupler is decoupled with 100nF and 10nF capacitors to filter

out transients from the switching power supply. System Connectors The schematic

incorporates a comprehensive set of headers that serve as the physical interface for all

external peripherals and power sources included I2C, SWD (Serial Wire Debug),

USART, Encoder, addition GPIO Pin and power from 3.3V to 24V Pin out for

necessary using.

3.5.2: PCB Layout Design

The transition from schematic to PCB layout is a critical phase, especially for

power systems where electromagnetic interference (EMI) and thermal management

dictate overall stability. The PCB for the Cart-Pole system is designed with a 2-layer

architecture, focusing on the following key strategies:

Figure 3.5.4: Optocouplers and Connectors Diagram

Power and Logic Segregation: To prevent high-current switching noise from

affecting the MCU, the board is strictly partitioned into a Power Zone (24V, 12V, H-

Bridge) and a Clean Logic Zone (STM32, Sensors). These zones are physically

separated by the isolation barrier of the optocouplers, ensuring that no ground loops

interfere with the 3.3V logic. High-Current Trace Routing: For the 150W power

requirement, the system handles a continuous current of approximately 6.25A. Traces

for the H-Bridge and motor outputs are designed with a minimum width of 80-100 mil

and reinforced with copper pours. Thermal vias are placed around the IRF3205S

MOSFETs to conduct heat to the bottom layer, utilizing the PCB surface as a passive

heatsink. Signal Integrity: High-speed signals, such as the 8MHz crystal traces and the

6N137 optocoupler outputs, are kept as short as possible. Decoupling capacitors (100nF)

are placed immediately adjacent to the VCC pins of the STM32 and IR2104 ICs to

suppress high-frequency transients. To minimize the cost and easy to handle, PCB size

is selected to 100mm x 100mm. The 3D Visualization is below:

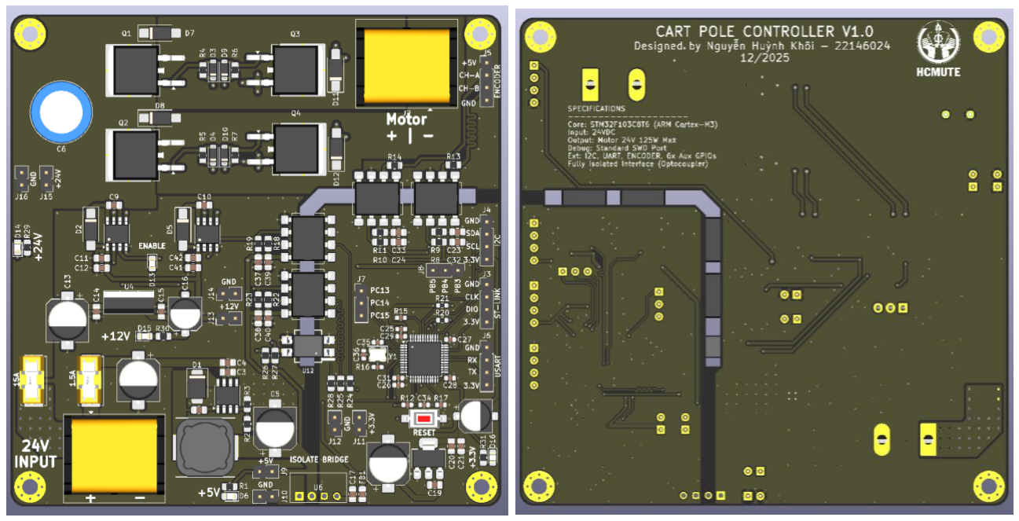
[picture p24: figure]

Figure 3.5.5: 3D Visualization of the Cart-Pole Control Board

## H-BRIDGE AND MOSFET DRIVER

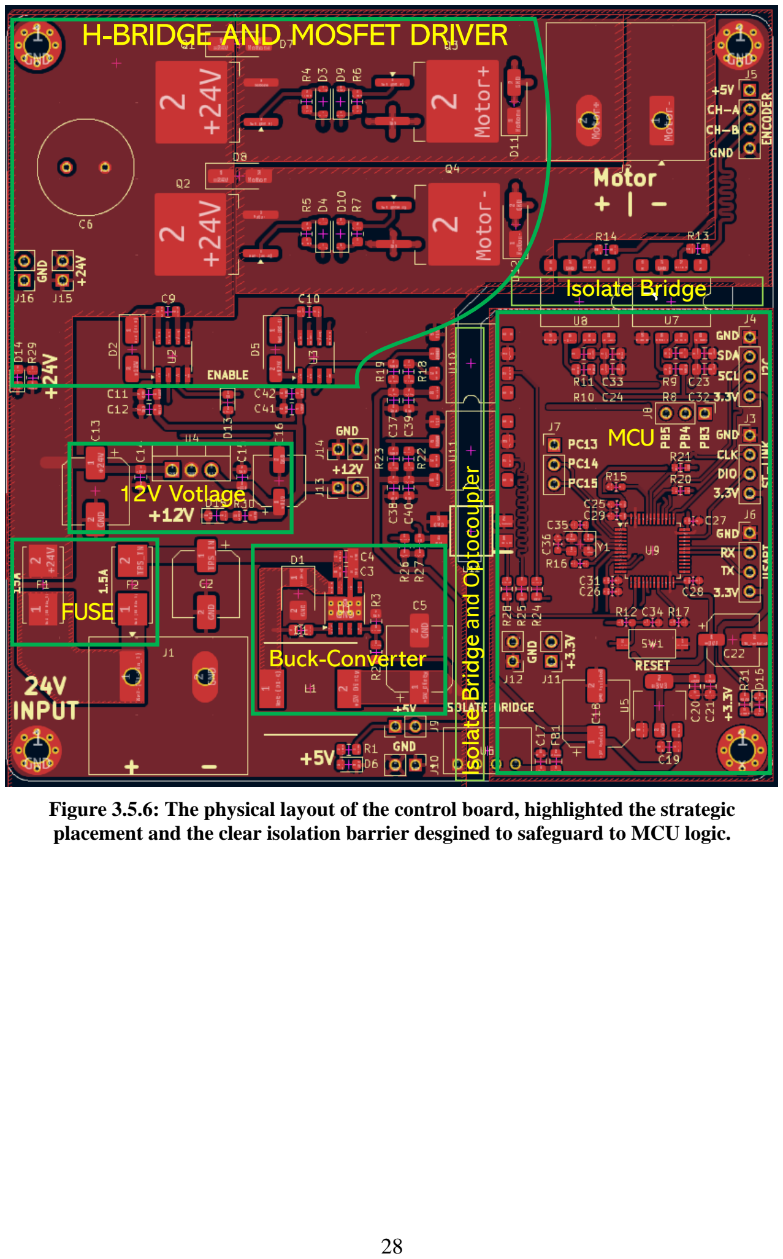
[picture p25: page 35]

d

Figure 3.5.6: The physical layout of the control board, highlighted the strategic placement and the clear isolation barrier desgined to safeguard to MCU logic.

12V Votlage

FUSE

Buck-Converter

MCU

r

Isolate Bridge and Optocoupler

Isolate Bridge

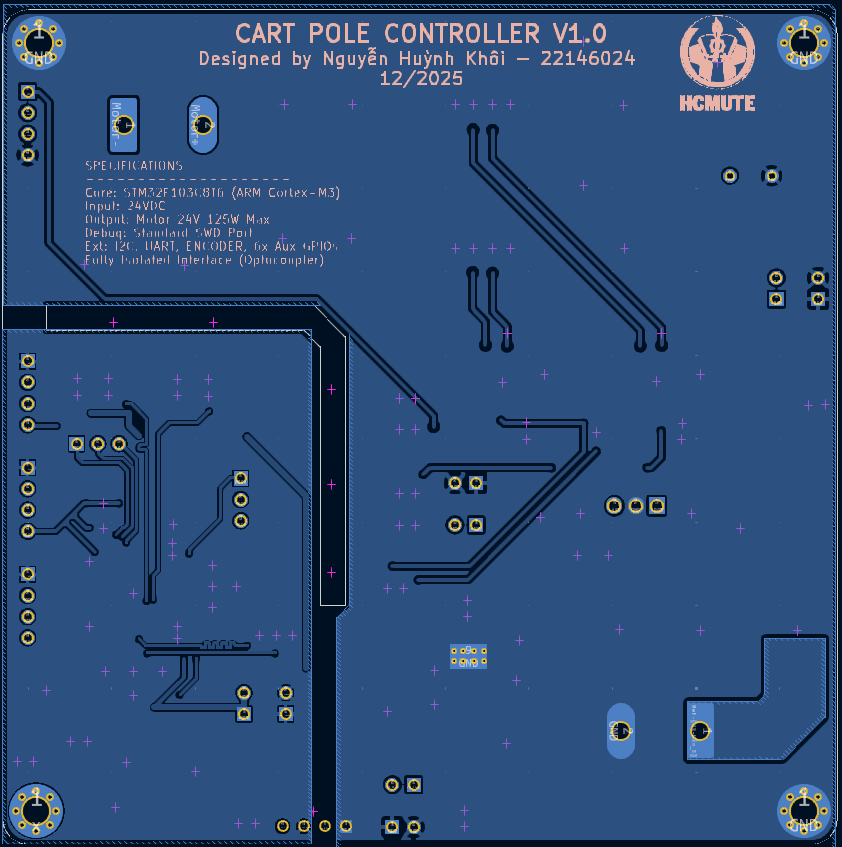
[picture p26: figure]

Figure 3.5.7: Back view of cooper traces and pads

CHAPTER IV: SOFTWARE DEVELOPMENT

### 4.1. Control Flowchart

Figure 4.1:Flowchart of Control Program

The software is designed to ensure a safe and predictable transition from power-

on to active balancing. The main execution flow consists of the following stages:

- Initialization: Upon reset, the MCU configures the system clock to 72MHz and

initializes all necessary peripherals, including GPIOs, Timers (PWM and Encoder), I2C

for the gyroscope, and USART for data logging.

- Calibration (Homing): The system performs a self-calibration routine to define

the "Zero" position of the cart and the absolute vertical angle of the pole. This step is

critical to eliminate mechanical offsets before the control loop engages.

- Wait Command (Idle State): The system enters a standby mode, monitoring

safety conditions and waiting for an enable signal (via a physical switch or software

command) to start the balancing process.

- PID Control Loop: Once enabled, the system enters a high-priority periodic loop.

It reads sensor data, computes the control output using the cascaded PID algorithm, and

updates the PWM duty cycle every 10ms.

### 4.2. STM32 Peripheral Configuration

### 4.2.1. Timer Encoder Mode

Instead of using software-based interrupts, the system utilizes TIM2 or TIM3 in

hardware Encoder Mode. It automatically decodes the quadrature signals (Phase A and

Phase B) from the encoder via pins PA0 and PA1. If the hardware counters increment

or decrement automatically based on the direction of rotation, providing instantaneous

and noise-resilient position and velocity data.

### 4.2.2. Timer PWM Generation

The PWM signals are generated using TIM3 (Advanced Control Timer) to drive

the H-Bridge through pins PA6 and PA7.Frequency set at 20kHz to ensure smooth

motor operation and eliminate audible high-frequency noise. We have formula to

calculate PWM frequency as:

fPWM =

fCLK
(PSC + 1) × (ARR + 1)

Set duty cycle is adjusted between 0% and 100% to regulate the average voltage

delivered to the DC motor, effectively controlling torque and speed. Clock of

micocontroller is 72MHz, we have:

fPWM =

72.000.000
(35 + 1) × (99 + 1)

= 20.000 Hz

Figure 4.2:TIM_2 Config for Encoder Mode

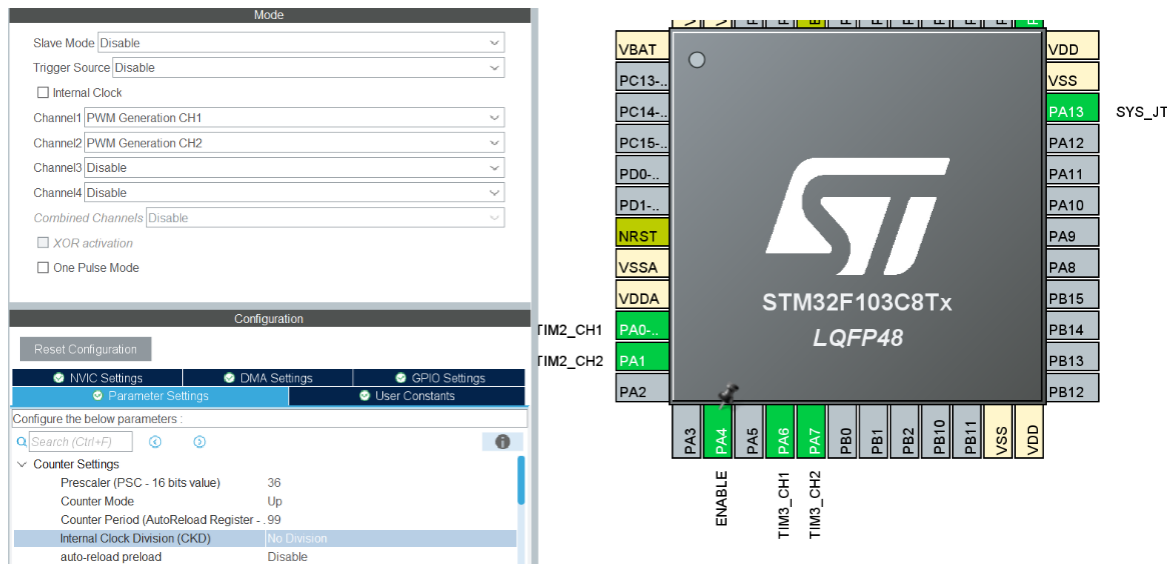
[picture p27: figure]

Figure 4.3: TIM_3 Config for PWM Generation

### 4.2.3. Timer Interrupt (10ms Periodic Task)

The stability of a PID controller depends heavily on a constant sampling rate (Ts). Timer

4 is configured to trigger an Interrupt Service Routine (ISR) every 10ms (100Hz). To

achieve 10ms, we got similar formula:

Tinterrupt =

(PSC + 1) × (ARR + 1)

fCLK

With fCLK = 72.000.000 Hz and Tinterrupt = 0,01 s:

0,01 =

(PSC + 1) × (ARR + 1)
72.000.000 => PSC = 7199 and ARR = 99

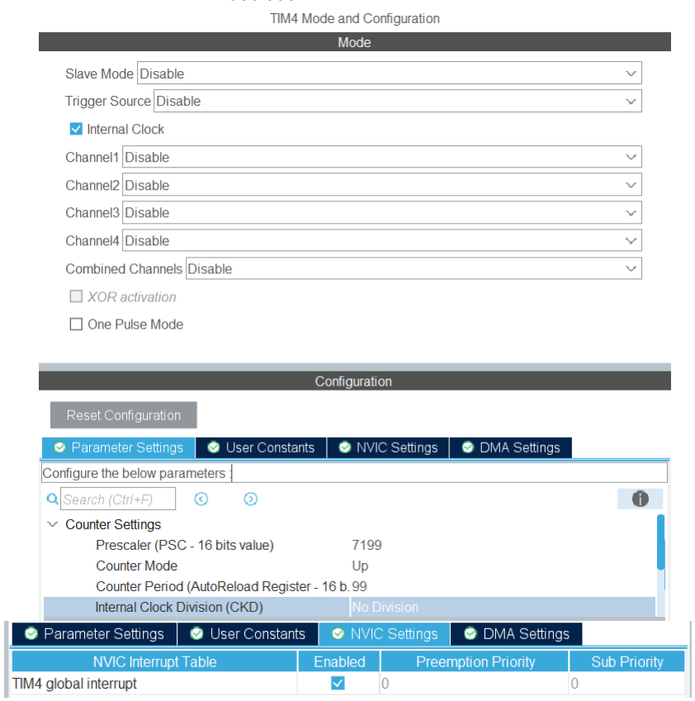
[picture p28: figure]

Figure 4.4:TIM_4 for Interrupt

Inside the interrupt, the MCU performs task including: Reads the tilt angle (θ)

from the Gyroscope via I2C. Reads the cart position (x) from the Encoder counter.

Executes the Cascaded PID calculations. Updates the PWM registers for immediate

motor response.

### 4.3. Controller Programming

The transition from the continuous mathematical PID formula to discrete C code

is achieved through discretization. We have continuous PID Formula:

u(t) = Kpe(t) + Ki ∫ e(t)dt + Kd

de(t)
dt

Discrete C-Code Implementation:

- Proportional Term (P): Reacts to the current error. p_term = Kp * error;
- Integral Term (I): Accumulates error over time to eliminate steady-state offset. Anti-

windup logic is applied to saturate this term. i_term += Ki * error * Ts;

- Derivative Term (D): Predicts future error by measuring the rate of change, helping

to dampen oscillations. d_term = Kd * (error - last_error) / Ts;

- Total Output: control_output = p_term + i_term + d_term; last_error = error;

CHAPTER V: RESULTS AND EVALUATION

### 5.1. Hardware Assembly and Power-on Self-Test

After completing the soldering of all surface-mount and through-hole

components, the board was visually inspected for solder bridges and cold joints. The

initial power-on test was performed hierarchically to verify the integrity of the power

management unit. Measurements taken using a digital multimeter confirmed that the

hierarchical power strategy is functioning correctly. All four required voltage rails are

present and stable are 24V DC fron main input from the power supply. 12V DC

regulated by the L7812. 5V DC stepped down by the TPS5430 buck converter. 3.3V

DC provided by the isolated B0505S and AMS1117.

### 5.2. Individual Functional Verification

Once the power rails were verified, each peripheral was tested individually using

dedicated firmware routines to ensure the STM32F103C8T6 could interact correctly

with the external hardware. The Serial Wire Debug (SWD) interface was successfully

validated using an ST-LINK V2 debugger. The STM32CubeIDE correctly identified the

STM32F103C8T6 core, confirming the integrity of the power supply, the 8MHz crystal

circuit, and the signal traces on pins PA13 (SWDIO) and PA14 (SWCLK). Firmware

Figure 5.1: PCB Control Interface Board for Cart Pole System flashing was performed without errors, and the real-time debugging capability was fully

functional. The hardware timer in Encoder Mode successfully captured pulses from the

quadrature encoder. By rotating the motor shaft manually, the MCU correctly

incremented and decremented the position counter, confirming the integrity of the

6N137 high-speed isolation path. The gyroscope was successfully detected on the I2C

bus. Raw data for the tilt angle (θ) and angular velocity were successfully retrieved,

confirming the correct implementation of the 4.7k Ω pull-up resistors and signal levels.

Real-time data was successfully transmitted to a PC via the USART1 interface. This

confirms that the system is ready for real-time PID tuning and telemetry. The TIM1

peripheral successfully outputted complementary PWM signals. Using an oscilloscope,

the signals were observed at the input of the IR2104 drivers after passing through the

6N137 optocouplers.

### 5.3. Technical Challenges and Failure Analysis

During the system integration phase, while the individual components operated

correctly, a hardware failure occurred in the H-bridge power stage during a test. This

section analyzes the failure and provides insights for future hardware iterations.

### 5.3.1. Incident Description

During the functional testing phase, specifically while applying the PWM signals

to the input pins of the IR2104 gate drivers to verify motor actuation, a critical hardware

failure occurred. While the system was powered, the 24V supply LED was observed

flashing continuously - indicating a severe voltage drop or a rapid oscillating short-

circuit condition. Immediately following this instability, the main fuse ruptured,

successfully isolating the power source. However, a subsequent diagnostic of the board

revealed extensive damage to the power stage. Two out of the four IRF3205S transistors

suffered a permanent drain-to-source short circuit. All four SS36 freewheeling diodes

were destroyed, likely due to exceeding their peak forward current ratings during the

failure. Both IR2104 integrated circuits became non-functional, potentially due to high-

voltage feedback from the MOSFET gates during the breakdown. This failure resulted

in the complete loss of the H-bridge's drive capability, preventing further real-time

testing on the H-Bridge.

### 5.3.2. Root Cause Analysis

After a thorough post-failure inspection of the PCB layout and physical

connections, a fundamental assembly oversight was identified as the primary cause of

the H-bridge breakdown. The failure originated from a missing connection between the

VS pin (Pin 6) of the IR2104 gate drivers and the source terminals of the high-side

MOSFETs (Q1 and Q3). The technical consequences of this missing connection are

Floating high-side reference, it mean that the VS pin serves as the floating return path

for the high-side gate drive. Without this connection, the bootstrap capacitor cannot

discharge correctly into the gate-source junction of the high-side MOSFET. This leaves

the gate in an undefined, "floating" state, susceptible to noise and unintentional

activation. Due to the lack of a proper reference, the high-side MOSFET likely remained

partially or fully active at the same time the low-side MOSFET was triggered. This

created a direct short-circuit path from the 24V rail to Ground through the bridge branch.

This catastrophic current surge is what caused the rapid flickering of the supply LEDs

and the immediate rupture of the 15A protection fuse. This hardware failure serves as a

critical lesson in the importance of meticulous verification of high-side driver return

paths in power electronics design.

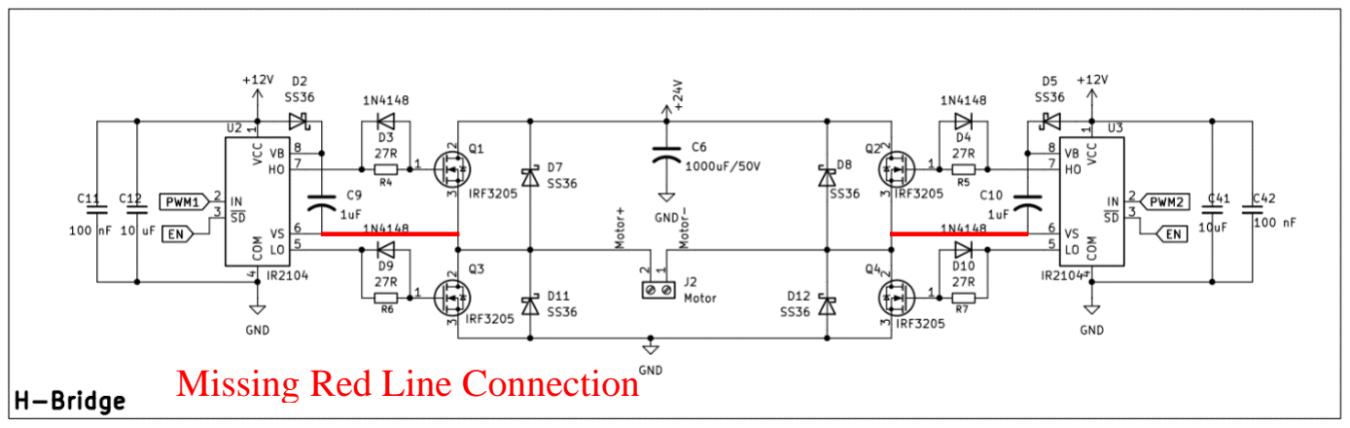
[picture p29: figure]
Missing Red Line Connection

Figure 5.2: Root Cause Short Circuit

CHAPTER VI: CONCLUSION

### 6.1. Conclusion

This project successfully established the foundational hardware and software

framework for a self-balancing Cart-Pole system powered by a 150W motor.

Throughout the development process, several key objectives were achieved: A robust

control board was designed and prototyped, featuring a hierarchical power system (24V,

12V, 5V, 3.3V) and a dual-layer isolation strategy using 6N137 and PC817 optocouplers

to safeguard the STM32 logic. The firmware effectively utilized the STM32's hardware

peripherals, including Timer Encoder Mode for precise position feedback, PWM

generation for motor control, and I2C communication for gyroscope data acquisition.

Individual sub-systems, including the power management unit, sensor interfaces, and

the SWD programming interface, were fully validated as functional. Although a critical

failure in the H-bridge power stage prevented the final physical balancing

demonstration, the incident provided a valuable opportunity for forensic engineering.

Identifying the most probable causes- such as EMI-induced shoot-through and inductive

back-EMF spikes - provided a deep understanding of high-power switching challenges.

While the project did not reach the final stage of long-term autonomous balancing, the

successful design of the complex 150W electronic platform and the implementation of

the cascaded PID logic constitute a significant milestone in mechatronics engineering.

### 6.2. Future Work

To evolve this project into a more reliable and advanced control platform, the

following developments are proposed: Fristly, repair the H-Bridge of the board and

make sure every components workable, then test one by one side of Half Bridge to

re-check if every correct. If the board funcional, applying the PID Loop is necessary and

run it on the hardware model to make sure PID is working. Tuning the PID is the next

step to achieve the fully funcional control board. After everything done, apply more

advanced control strategies such as Linear Quadratic Regulator (LQR), Fuzzy Logic

Control to improving program skill is considerable.

CITIATION

[1] Ogata, K. (2010). Modern Control Engineering. 5th Ed. Prentice Hall.

[2]Nise, N. S. (2015). Control Systems Engineering. 7th Ed. John Wiley & Sons.

[3]Visioli, A. (2006). Practical PID Control. Springer.

[4] V. L. Chương, " MODEL 3. VELOCITY CONTROL FOR DC SERVO MOTORS"

Lecture Notes, Faculty of Mechanical Engineering, Ho Chi Minh City University of

Technology and Engineering.

[5] V. L. Chương, " MODEL 4. POSITION CONTROL FOR DC SERVO MOTORS"

Lecture Notes, Faculty of Mechanical Engineering, Ho Chi Minh City University of

Technology and Engineering.

[6] MathWorks, "Designing Cascade Control System with PI Controllers," MathWorks

Help Center. [Online]. Available:

https://www.mathworks.com/help/control/ug/designing-cascade-control-system-

with-pi-controllers.html. (https://www.mathworks.com/help/control/ug/designing-cascade-control-system-with-pi-controllers.html)

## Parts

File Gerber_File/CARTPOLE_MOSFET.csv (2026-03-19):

Reference | Qty | Value | DNP | Exclude from BOM | Exclude from Board | Footprint | Datasheet
C1,C23,C24,C37,C38 | 5 | 10 nF |  |  |  | Capacitor_SMD:C_0805_2012Metric_Pad1.18x1.45mm_HandSolder | https://www.thegioiic.com/tu-gom-0805-10nf-50v
C2,C13 | 2 | 100uF/50V |  |  |  | Capacitor_SMD:CP_Elec_8x10.5 | https://www.thegioiic.com/tu-nhom-smd-100uf-50v-8x10-5mm
C3 | 1 | 100nF |  |  |  | Capacitor_SMD:C_0805_2012Metric_Pad1.18x1.45mm_HandSolder | https://www.thegioiic.com/tu-gom-0805-100nf-0-1uf-50v
C4,C17,C20,C41 | 4 | 10uF |  |  |  | Capacitor_SMD:C_0805_2012Metric_Pad1.18x1.45mm_HandSolder | https://www.thegioiic.com/tu-gom-0805-10uf-50v
C5 | 1 | 220uF |  |  |  | Capacitor_SMD:CP_Elec_8x10.5 | https://www.thegioiic.com/tu-nhom-smd-220uf-25v-8x10-5mm
C6 | 1 | 1000uF/50V |  |  |  | Capacitor_THT:C_Radial_D12.5mm_H25.0mm_P5.00mm | https://www.thegioiic.com/tu-hoa-1000uf-50v-13x25mm-xuyen-lo
C9,C10 | 2 | 1uF |  |  |  | Capacitor_SMD:C_0805_2012Metric_Pad1.18x1.45mm_HandSolder | https://www.thegioiic.com/tu-gom-0805-1uf-50v
C11,C15,C19,C21,C32,C33,C39,C40,C42 | 9 | 100 nF |  |  |  | Capacitor_SMD:C_0805_2012Metric_Pad1.18x1.45mm_HandSolder | https://www.thegioiic.com/tu-gom-0805-100nf-0-1uf-50v
C12 | 1 | 10 uF |  |  |  | Capacitor_SMD:C_0805_2012Metric_Pad1.18x1.45mm_HandSolder | https://www.thegioiic.com/tu-gom-0805-10uf-50v
C14 | 1 | 330 nF |  |  |  | Capacitor_SMD:C_0805_2012Metric_Pad1.18x1.45mm_HandSolder | https://www.thegioiic.com/tu-gom-0805-330nf-50v
C16,C22 | 2 | 47uF/25V |  |  |  | Capacitor_SMD:CP_Elec_6.3x5.4 | https://www.thegioiic.com/tu-nhom-smd-47uf-25v-6-3x5-4mm
C18 | 1 | 100uF/25V |  |  |  | Capacitor_SMD:CP_Elec_8x10.5 | https://www.thegioiic.com/tu-nhom-smd-100uf-50v-8x10-5mm
C25,C31 | 2 | 10uF/25V |  |  |  | Capacitor_SMD:C_0603_1608Metric | https://www.thegioiic.com/tu-gom-0603-10uf-25v
C26,C27,C28,C29 | 4 | 100 nF |  |  |  | Capacitor_SMD:C_0603_1608Metric | https://www.thegioiic.com/tu-gom-0603-100nf-0-1uf-50v
C34 | 1 | 100nF |  |  |  | Capacitor_SMD:C_0603_1608Metric | https://www.thegioiic.com/tu-gom-0603-100nf-0-1uf-50v
C35,C36 | 2 | 10pF |  |  |  | Capacitor_SMD:C_0603_1608Metric | https://www.thegioiic.com/tu-gom-0603-10pf-50v
D1 | 1 | 60V-4A |  |  |  | Diode_SMD:D_SMB | https://www.thegioiic.com/ss56-smb-schottky-barrier-diodes-5a-60v-do-214aa
D2,D5,D7,D8,D11,D12 | 6 | SS36 |  |  |  | Diode_SMD:D_SMA_Handsoldering | https://www.thegioiic.com/ss36-sma-diode-schottky-3a
D3,D4,D9,D10 | 4 | 1N4148 |  |  |  | Diode_SMD:D_SOD-123 | https://www.thegioiic.com/1n4148w-e3-18-diode-gen-purp-75v-150ma-sod123
D6 | 1 | 5V_LED |  |  |  | LED_SMD:LED_0805_2012Metric_Pad1.15x1.40mm_HandSolder | https://www.thegioiic.com/led-do-0805-dan-smd-trong-suot-harvatek
D13 | 1 | LED |  |  |  | LED_SMD:LED_0805_2012Metric_Pad1.15x1.40mm_HandSolder | https://www.thegioiic.com/led-do-0805-dan-smd-trong-suot-harvatek
D14 | 1 | 24V_LED |  |  |  | LED_SMD:LED_0805_2012Metric_Pad1.15x1.40mm_HandSolder | https://www.thegioiic.com/led-do-0805-dan-smd-trong-suot-harvatek
D15 | 1 | 12V_LED |  |  |  | LED_SMD:LED_0805_2012Metric_Pad1.15x1.40mm_HandSolder | https://www.thegioiic.com/led-do-0805-dan-smd-trong-suot-harvatek
D16 | 1 | 3V3_LED |  |  |  | LED_SMD:LED_0805_2012Metric_Pad1.15x1.40mm_HandSolder | https://www.thegioiic.com/led-do-0805-dan-smd-trong-suot-harvatek
F1 | 1 | 15A |  |  |  | Fuse:Fuseholder_Littelfuse_Nano2_154x | https://www.thegioiic.com/de-cau-chi-1808-dan-smd
F2 | 1 | 1.5A |  |  |  | Fuse:Fuseholder_Littelfuse_Nano2_154x | https://www.thegioiic.com/de-cau-chi-1808-dan-smd
FB1 | 1 | 120R-2A |  |  |  | Capacitor_SMD:C_0805_2012Metric_Pad1.18x1.45mm_HandSolder | https://www.thegioiic.com/cbw201209u121t-ferrite-beads-2a-120-ohm-0805
H5,H6,H7,H8 | 4 | ~ |  | Excluded from BOM |  | MountingHole:MountingHole_3.2mm_M3_Pad_Via | ~
J1 | 1 | 24VDC IN |  |  |  | TerminalBlock:TerminalBlock_Ningbo-Kagnex_HB9500_1x02_P9.5mm | https://www.thegioiic.com/kf7-62-2-terminal-khoi-han-pcb-2-cuc-20a-300v-7-62mm
J2 | 1 | Motor |  |  |  | TerminalBlock:TerminalBlock_Ningbo-Kagnex_HB9500_1x02_P9.5mm | https://www.thegioiic.com/hb9500-2-terminal-khoi-han-pcb-2-cuc-25a-300v-9-5mm
J3 | 1 | STLINK_DEBUG |  |  |  | Connector_PinHeader_2.54mm:PinHeader_1x04_P2.54mm_Vertical | ~
J4 | 1 | I2C |  |  |  | Connector_PinHeader_2.54mm:PinHeader_1x04_P2.54mm_Vertical | ~
J5 | 1 | ENCODER |  |  |  | Connector_PinHeader_2.54mm:PinHeader_1x04_P2.54mm_Vertical | ~
J6 | 1 | USART |  |  |  | Connector_PinHeader_2.54mm:PinHeader_1x04_P2.54mm_Vertical | ~
J7 | 1 | PC13-PC15 |  |  |  | Connector_PinHeader_2.54mm:PinHeader_1x03_P2.54mm_Vertical | ~
J8 | 1 | PB3-PB5 |  |  |  | Connector_PinHeader_2.54mm:PinHeader_1x03_P2.54mm_Vertical | ~
J9 | 1 | 5V |  |  |  | Connector_PinHeader_2.54mm:PinHeader_1x02_P2.54mm_Vertical | ~
J10,J12,J14,J16 | 4 | GND |  |  |  | Connector_PinHeader_2.54mm:PinHeader_1x02_P2.54mm_Vertical | ~
J11 | 1 | 3.3V |  |  |  | Connector_PinHeader_2.54mm:PinHeader_1x02_P2.54mm_Vertical | ~
J13 | 1 | 12V |  |  |  | Connector_PinHeader_2.54mm:PinHeader_1x02_P2.54mm_Vertical | ~
J15 | 1 | 24V |  |  |  | Connector_PinHeader_2.54mm:PinHeader_1x02_P2.54mm_Vertical | ~
L1 | 1 | 47uH |  |  |  | CDRH127_LDNP-221MC:INDPM120120X800N | https://www.thegioiic.com/cuon-cam-dan-smd-cdrh127-1280-470-47uh-3-25a
Q1,Q2,Q3,Q4 | 4 | IRF3205 |  |  |  | Package_TO_SOT_SMD:TO-263-2 | https://www.thegioiic.com/irf3205s-mosfet-kenh-n-55v-110a-d2pak
R1,R26 | 2 | 1k |  |  |  | Resistor_SMD:R_0805_2012Metric_Pad1.20x1.40mm_HandSolder | https://www.thegioiic.com/dien-tro-1-kohm-0805-1-
R2,R9,R11,R18,R22,R27,R29 | 7 | 10k |  |  |  | Resistor_SMD:R_0805_2012Metric_Pad1.20x1.40mm_HandSolder | https://www.thegioiic.com/dien-tro-10-kohm-0805-1-
R3,R30 | 2 | 3k3 |  |  |  | Resistor_SMD:R_0805_2012Metric_Pad1.20x1.40mm_HandSolder | https://www.thegioiic.com/dien-tro-3-3-kohm-0805-1-
R4,R5,R6,R7 | 4 | 27R |  |  |  | Resistor_SMD:R_0805_2012Metric_Pad1.20x1.40mm_HandSolder | https://www.thegioiic.com/dien-tro-27-ohm-0805-1-
R8,R10,R19,R23 | 4 | 4k7 |  |  |  | Resistor_SMD:R_0805_2012Metric_Pad1.20x1.40mm_HandSolder | https://www.thegioiic.com/dien-tro-4-7-kohm-0805-1-
R12,R15,R17 | 3 | 10k |  |  |  | Capacitor_SMD:C_0603_1608Metric | https://www.thegioiic.com/dien-tro-10-kohm-0603-1-
R13,R14,R24,R25,R28 | 5 | 220R |  |  |  | Resistor_SMD:R_0805_2012Metric_Pad1.20x1.40mm_HandSolder | https://www.thegioiic.com/dien-tro-220-ohm-0805-1-
R16 | 1 | 0 |  |  |  | Capacitor_SMD:C_0603_1608Metric | https://www.thegioiic.com/dien-tro-0-ohm-0603-5-
R20,R21 | 2 | 4k7 |  |  |  | Resistor_SMD:R_0603_1608Metric | https://www.thegioiic.com/dien-tro-4-7-kohm-0603-1-
R31 | 1 | 330R |  |  |  | Resistor_SMD:R_0805_2012Metric_Pad1.20x1.40mm_HandSolder | https://www.thegioiic.com/dien-tro-330-ohm-0805-1-
SW1 | 1 | SW_Push |  |  |  | Button_Switch_SMD:SW_SPST_CK_RS282G05A3 | https://www.thegioiic.com/nut-nhan-3x6mm-cao-2-5mm-2-chan-smd-dau-do
U1 | 1 | TPS5430DDA |  |  |  | Package_SO:TI_SO-PowerPAD-8_ThermalVias | https://www.thegioiic.com/tps5430ddar-ic-dieu-chinh-giam-ap-3a-8-soic
U2,U3 | 2 | IR2104 |  |  |  | Package_SO:SOIC-8_3.9x4.9mm_P1.27mm | https://www.thegioiic.com/ir2104spbf-mosfet-2-ngo-ra-360-ma-20v-8-soic
U4 | 1 | L7812 |  |  |  | Package_TO_SOT_THT:TO-220-3_Vertical | https://www.thegioiic.com/l7812cd2t-cn-ic-on-ap-12v-1-5a
U5 | 1 | AMS1117-3.3 |  |  |  | Package_TO_SOT_SMD:SOT-223-3_TabPin2 | https://www.thegioiic.com/ams1117-3-3v-ic-on-ap-3-3v-1a-sot-223
U6 | 1 | B0505S |  |  |  | RFM-0505S:CONV_RFM-0505S | https://www.thegioiic.com/b0505s-1wr3-chuyen-doi-dc-dc-vao-5v-ra-5v-1w
U7,U8,U10,U11 | 4 | 6N137 |  |  |  | Package_DIP:SMDIP-8_W9.53mm_Clearance8mm | https://www.thegioiic.com/el6n137s-smd-logic-output-optoisolator-5000vrms-1-channel-8-smd
U9 | 1 | STM32F103C8T6 |  |  |  | Package_QFP:LQFP-48_7x7mm_P0.5mm | https://www.st.com/resource/en/datasheet/stm32f103c8.pdf
U12 | 1 | PC817X2 |  |  |  | PC817X2NIP0F:SOP254P975X460-4N | https://www.thegioiic.com/pc817x2nipw-optoisolator-transistor-output-5000vrms-1-channel-sop-4
Y1 | 1 | 8Mhz |  |  |  | Crystal:Crystal_SMD_3225-4Pin_3.2x2.5mm | https://www.thegioiic.com/thach-anh-8mhz-5032-2-chan-smd

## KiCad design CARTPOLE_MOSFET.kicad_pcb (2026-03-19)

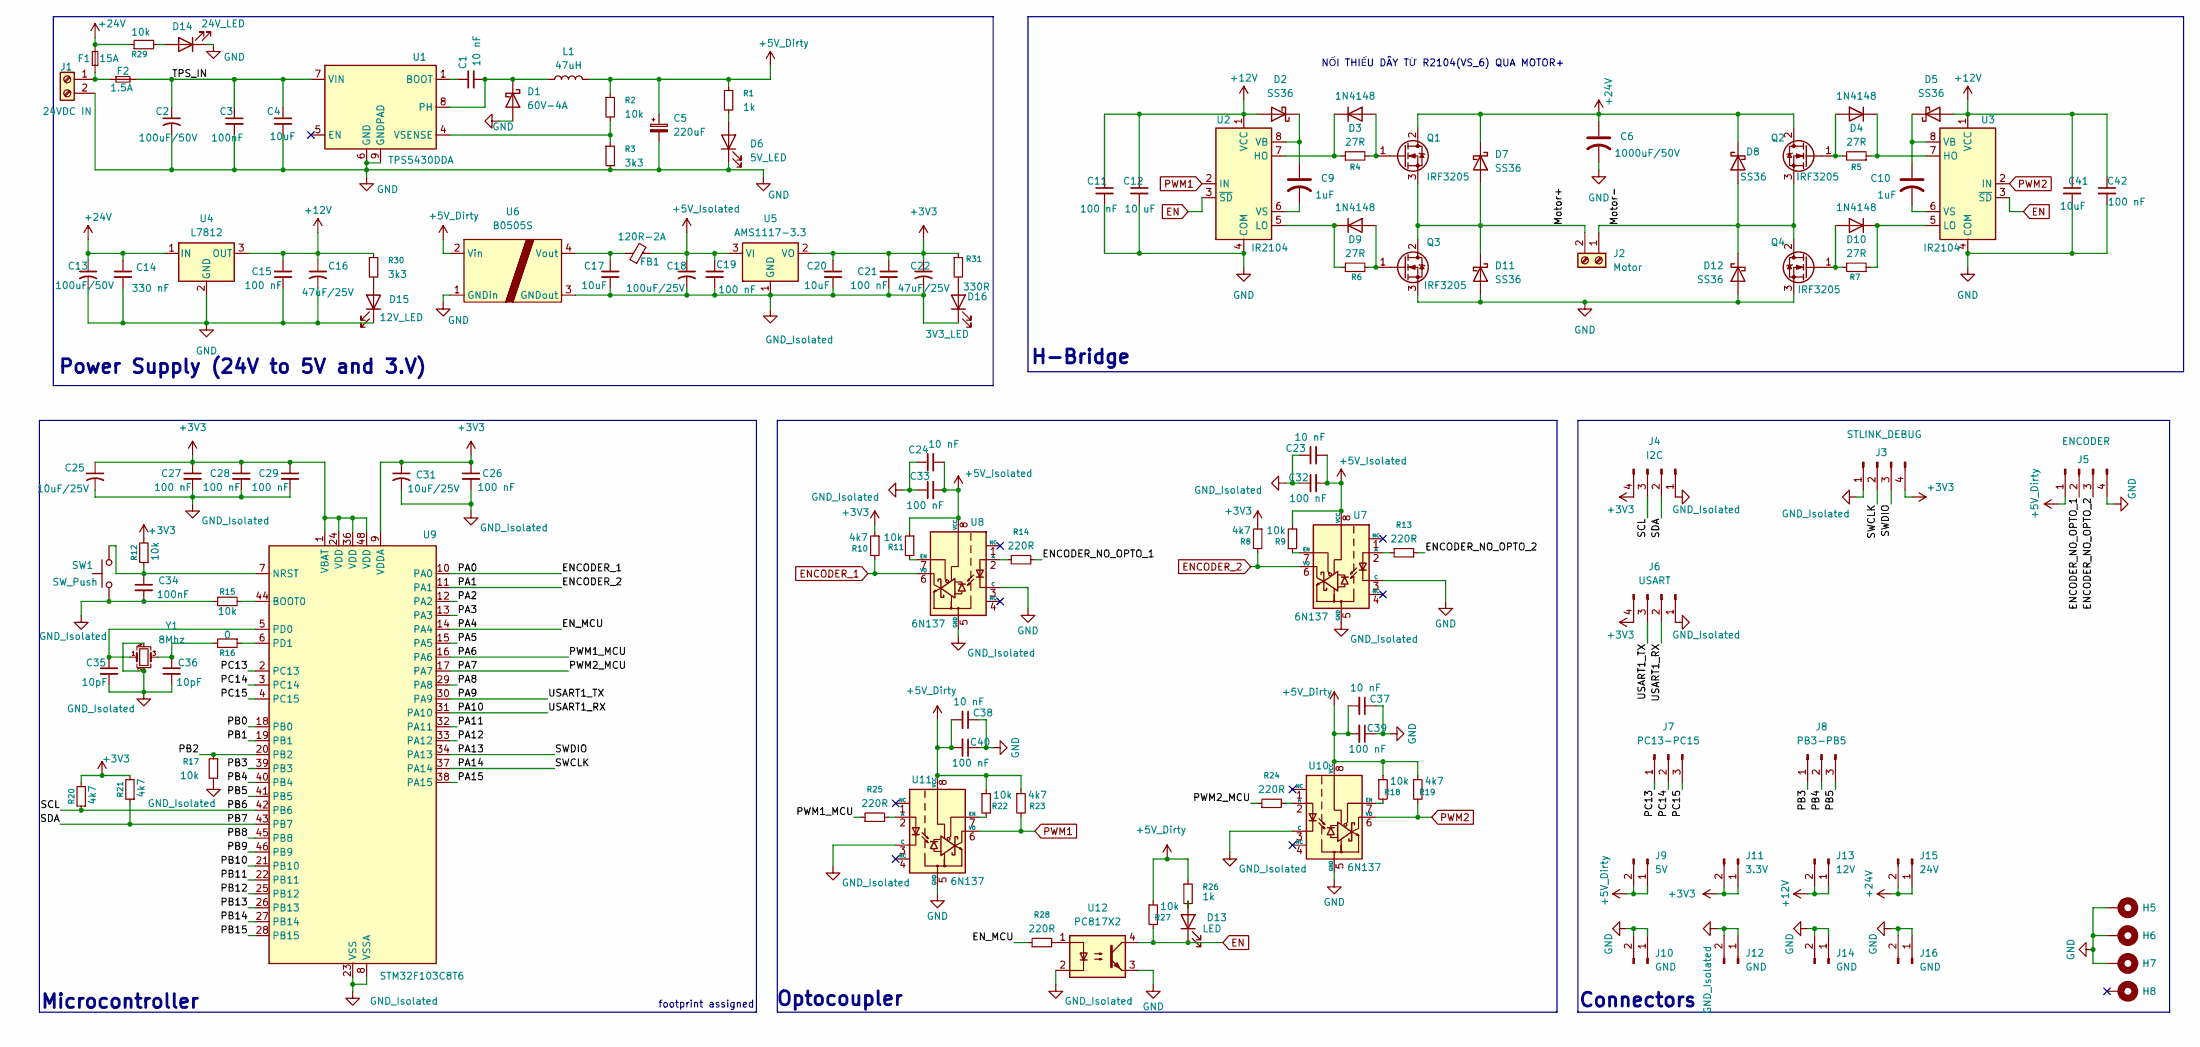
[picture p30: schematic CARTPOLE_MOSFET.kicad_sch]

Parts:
C1, C23, C24, C37, C38: 10 nF; C_0805_2012Metric_Pad1.18x1.45mm_HandSolder
C2, C13: 100uF/50V; CP_Elec_8x10.5
C3: 100nF; C_0805_2012Metric_Pad1.18x1.45mm_HandSolder
C4, C17, C20, C41: 10uF; C_0805_2012Metric_Pad1.18x1.45mm_HandSolder
C5: 220uF; CP_Elec_8x10.5
C6: 1000uF/50V; C_Radial_D12.5mm_H25.0mm_P5.00mm
C9, C10: 1uF; C_0805_2012Metric_Pad1.18x1.45mm_HandSolder
C11, C15, C19, C21, C32, C33, C39, C40, C42: 100 nF; C_0805_2012Metric_Pad1.18x1.45mm_HandSolder
C12: 10 uF; C_0805_2012Metric_Pad1.18x1.45mm_HandSolder
C14: 330 nF; C_0805_2012Metric_Pad1.18x1.45mm_HandSolder
C16, C22: 47uF/25V; CP_Elec_6.3x5.4
C18: 100uF/25V; CP_Elec_8x10.5
C25, C31: 10uF/25V; C_0603_1608Metric
C26, C27, C28, C29: 100 nF; C_0603_1608Metric
C34: 100nF; C_0603_1608Metric
C35, C36: 10pF; C_0603_1608Metric
D1: 60V-4A; D_SMB
D2, D5, D7, D8, D11, D12: SS36; D_SMA_Handsoldering
D3, D4, D9, D10: 1N4148; D_SOD-123
D6: 5V_LED; LED_0805_2012Metric_Pad1.15x1.40mm_HandSolder
D13: LED; LED_0805_2012Metric_Pad1.15x1.40mm_HandSolder
D14: 24V_LED; LED_0805_2012Metric_Pad1.15x1.40mm_HandSolder
D15: 12V_LED; LED_0805_2012Metric_Pad1.15x1.40mm_HandSolder
D16: 3V3_LED; LED_0805_2012Metric_Pad1.15x1.40mm_HandSolder
F1: 15A; Fuseholder_Littelfuse_Nano2_154x
F2: 1.5A; Fuseholder_Littelfuse_Nano2_154x
FB1: 120R-2A; C_0805_2012Metric_Pad1.18x1.45mm_HandSolder
H5, H6, H7, H8: MountingHole_3.2mm_M3_Pad_Via
J1: 24VDC IN; TerminalBlock_Ningbo-Kagnex_HB9500_1x02_P9.5mm
J2: Motor; TerminalBlock_Ningbo-Kagnex_HB9500_1x02_P9.5mm
J3: STLINK_DEBUG; PinHeader_1x04_P2.54mm_Vertical
J4: I2C; PinHeader_1x04_P2.54mm_Vertical
J5: ENCODER; PinHeader_1x04_P2.54mm_Vertical
J6: USART; PinHeader_1x04_P2.54mm_Vertical
J7: PC13-PC15; PinHeader_1x03_P2.54mm_Vertical
J8: PB3-PB5; PinHeader_1x03_P2.54mm_Vertical
J9: 5V; PinHeader_1x02_P2.54mm_Vertical
J10, J12, J14, J16: GND; PinHeader_1x02_P2.54mm_Vertical
J11: 3.3V; PinHeader_1x02_P2.54mm_Vertical
J13: 12V; PinHeader_1x02_P2.54mm_Vertical
J15: 24V; PinHeader_1x02_P2.54mm_Vertical
L1: 47uH; INDPM120120X800N
Q1, Q2, Q3, Q4: IRF3205; TO-263-2
R1, R26: 1k; R_0805_2012Metric_Pad1.20x1.40mm_HandSolder
R2, R9, R11, R18, R22, R27, R29: 10k; R_0805_2012Metric_Pad1.20x1.40mm_HandSolder
R3, R30: 3k3; R_0805_2012Metric_Pad1.20x1.40mm_HandSolder
R4, R5, R6, R7: 27R; R_0805_2012Metric_Pad1.20x1.40mm_HandSolder
R8, R10, R19, R23: 4k7; R_0805_2012Metric_Pad1.20x1.40mm_HandSolder
R12, R15, R17: 10k; C_0603_1608Metric
R13, R14, R24, R25, R28: 220R; R_0805_2012Metric_Pad1.20x1.40mm_HandSolder
R16: 0; C_0603_1608Metric
R20, R21: 4k7; R_0603_1608Metric
R31: 330R; R_0805_2012Metric_Pad1.20x1.40mm_HandSolder
SW1: SW_Push; SW_SPST_CK_RS282G05A3
U1: TPS5430DDA; TI_SO-PowerPAD-8_ThermalVias
U2, U3: IR2104; SOIC-8_3.9x4.9mm_P1.27mm
U4: L7812; TO-220-3_Vertical
U5: AMS1117-3.3; SOT-223-3_TabPin2
U6: B0505S; CONV_RFM-0505S
U7, U8, U10, U11: 6N137; SMDIP-8_W9.53mm_Clearance8mm
U9: STM32F103C8T6; LQFP-48_7x7mm_P0.5mm
U12: PC817X2; SOP254P975X460-4N
Y1: 8Mhz; Crystal_SMD_3225-4Pin_3.2x2.5mm

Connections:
+3V3: C20.1, C21.1, C22.1, C25.1, C26.1, C27.1, C28.1, C29.1, C31.1, J3.4, J4.4, J6.4, J11.1, J11.2, R8.1, R10.1, R12.2, R20.2, R21.2, R31.1, U5.2 (VO), U9.1 (VBAT), U9.9 (VDDA), U9.24 (VDD), U9.36 (VDD), U9.48 (VDD)
+5V_Dirty: C5.1, C37.2, C38.2, C39.2, C40.2, J5.1, J9.1, J9.2, L1.2, R1.1, R2.1, R18.1, R19.1, R22.1, R23.1, R26.1, R27.1, U6.2 (Vin), U10.8 (VCC), U11.8 (VCC)
+5V_Isolated: C18.1, C19.1, C23.2, C24.2, C32.2, C33.2, FB1.2, R9.1, R11.1, U5.3 (VI), U7.8 (VCC), U8.8 (VCC)
+12V: C11.1, C12.1, C15.1, C16.1, C41.1, C42.1, D2.2 (A), D5.2 (A), J13.1, J13.2, R30.1, U2.1 (VCC), U3.1 (VCC), U4.3 (OUT)
+24V: C6.1, C13.1, C14.1, D7.1 (K), D8.1 (K), F1.2, J15.1, J15.2, Q1.2 (D), Q2.2 (D), R29.1, U4.1 (IN)
/ENCODER_NO_OPTO_1: J5.2, R14.1
/ENCODER_NO_OPTO_2: J5.3, R13.1
/EN_MCU: R28.1, U9.14 (PA4)
/Motor+: D7.2 (A), D11.1 (K), J2.2, Q1.3 (S), Q3.2 (D)
/Motor-: D8.2 (A), D12.1 (K), J2.1, Q2.3 (S), Q4.2 (D)
/PA2: U9.12 (PA2)
/PA3: U9.13 (PA3)
/PA5: U9.15 (PA5)
/PA6: R25.1, U9.16 (PA6)
/PA7: R24.1, U9.17 (PA7)
/PA8: U9.29 (PA8)
/PA9: J6.3, U9.30 (PA9)
/PA10: J6.2, U9.31 (PA10)
/PA11: U9.32 (PA11)
/PA12: U9.33 (PA12)
/PA13: J3.3, U9.34 (PA13)
/PA14: J3.2, U9.37 (PA14)
/PA15: U9.38 (PA15)
/PB0: U9.18 (PB0)
/PB1: U9.19 (PB1)
/PB2: R17.1, U9.20 (PB2)
/PB3: J8.1, U9.39 (PB3)
/PB4: J8.2, U9.40 (PB4)
/PB5: J8.3, U9.41 (PB5)
/PB6: J4.3, R20.1, U9.42 (PB6)
/PB7: J4.2, R21.1, U9.43 (PB7)
/PB8: U9.45 (PB8)
/PB9: U9.46 (PB9)
/PB10: U9.21 (PB10)
/PB11: U9.22 (PB11)
/PB12: U9.25 (PB12)
/PB13: U9.26 (PB13)
/PB14: U9.27 (PB14)
/PB15: U9.28 (PB15)
/PC13: J7.1, U9.2 (PC13)
/PC14: J7.2, U9.3 (PC14)
/PC15: J7.3, U9.4 (PC15)
/TPS_IN: C2.1, C3.1, C4.1, F2.2, U1.7 (VIN)
EN: D13.1 (K), R27.2, U2.3 (~SD), U3.3 (~SD), U12.4
ENCODER_1: R10.2, U8.6 (VO), U9.10 (PA0)
ENCODER_2: R8.2, U7.6 (VO), U9.11 (PA1)
GND: C2.2, C3.2, C4.2, C5.2, C6.2, C11.2, C12.2, C13.2, C14.2, C15.2, C16.2, C37.1, C38.1, C39.1, C40.1, C41.2, C42.2, D1.2 (A), D6.1 (K), D11.2 (A), D12.2 (A), D14.1 (K), D15.1 (K), H5.1, H6.1, H7.1, J1.2, J5.4, J10.1, J10.2, J14.1, J14.2, J16.1, J16.2, Q3.3 (S), Q4.3 (S), R3.2, U1.6 (GND), U1.9 (GNDPAD), U2.4 (COM), U3.4 (COM), U4.2 (GND), U6.1 (GNDin), U7.3 (C), U8.3 (C), U10.5 (GND), U11.5 (GND), U12.3
GND_Isolated: C17.2, C18.2, C19.2, C20.2, C21.2, C22.2, C23.1, C24.1, C25.2, C26.2, C27.2, C28.2, C29.2, C31.2, C32.1, C33.1, C34.2, C35.2, C36.2, D16.1 (K), J3.1, J4.1, J6.1, J12.1, J12.2, R15.1, R17.2, SW1.1, U5.1 (GND), U6.3 (GNDout), U7.5 (GND), U8.5 (GND), U9.8 (VSSA), U9.23 (VSS), U9.35 (VSS), U9.47 (VSS), U10.3 (C), U11.3 (C), U12.2, Y1.2, Y1.4
unnamed: C36.1, R16.2, Y1.3
unnamed: C1.2, D1.1 (K), L1.1, U1.8 (PH)
unnamed: C9.1, D2.1 (K), U2.8 (VB)
unnamed: D3.2 (A), Q1.1 (G), R4.2
unnamed: D3.1 (K), R4.1, U2.7 (HO)
unnamed: D4.2 (A), Q2.1 (G), R5.2
unnamed: D4.1 (K), R5.1, U3.7 (HO)
unnamed: C10.1, D5.1 (K), U3.8 (VB)
unnamed: D6.2 (A), R1.2
unnamed: D9.2 (A), Q3.1 (G), R6.2
unnamed: D9.1 (K), R6.1, U2.5 (LO)
unnamed: D10.2 (A), Q4.1 (G), R7.2
unnamed: D10.1 (K), R7.1, U3.5 (LO)
unnamed: D13.2 (A), R26.2
unnamed: D14.2 (A), R29.2
unnamed: D15.2 (A), R30.2
unnamed: D16.2 (A), R31.2
unnamed: F1.1, F2.1, J1.1
unnamed: R28.2, U12.1
unnamed: C1.1, U1.1 (BOOT)
unnamed: R2.2, R3.1, U1.4 (VSENSE)
unnamed: C9.2, U2.6 (VS)
unnamed: C10.2, U3.6 (VS)
unnamed: C17.1, FB1.1, U6.4 (Vout)
unnamed: R13.2, U7.2 (A)
unnamed: R9.2, U7.7 (EN)
unnamed: R14.2, U8.2 (A)
unnamed: R11.2, U8.7 (EN)
unnamed: R15.2, U9.44 (BOOT0)
unnamed: C34.1, R12.1, SW1.2, U9.7 (NRST)
unnamed: C35.1, U9.5 (PD0), Y1.1
unnamed: R16.1, U9.6 (PD1)
unnamed: R24.2, U10.2 (A)
unnamed: R18.2, U10.7 (EN)
unnamed: R25.2, U11.2 (A)
unnamed: R22.2, U11.7 (EN)
PWM1: R23.2, U2.2 (IN), U11.6 (VO)
PWM2: R19.2, U3.2 (IN), U10.6 (VO)

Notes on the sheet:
Connectors
Microcontroller
footprint assigned
H-Bridge
Power Supply (24V to 5V and 3.V)
Optocoupler
NỐI THIẾU DÂY TỪ R2104(VS_6) QUA MOTOR+

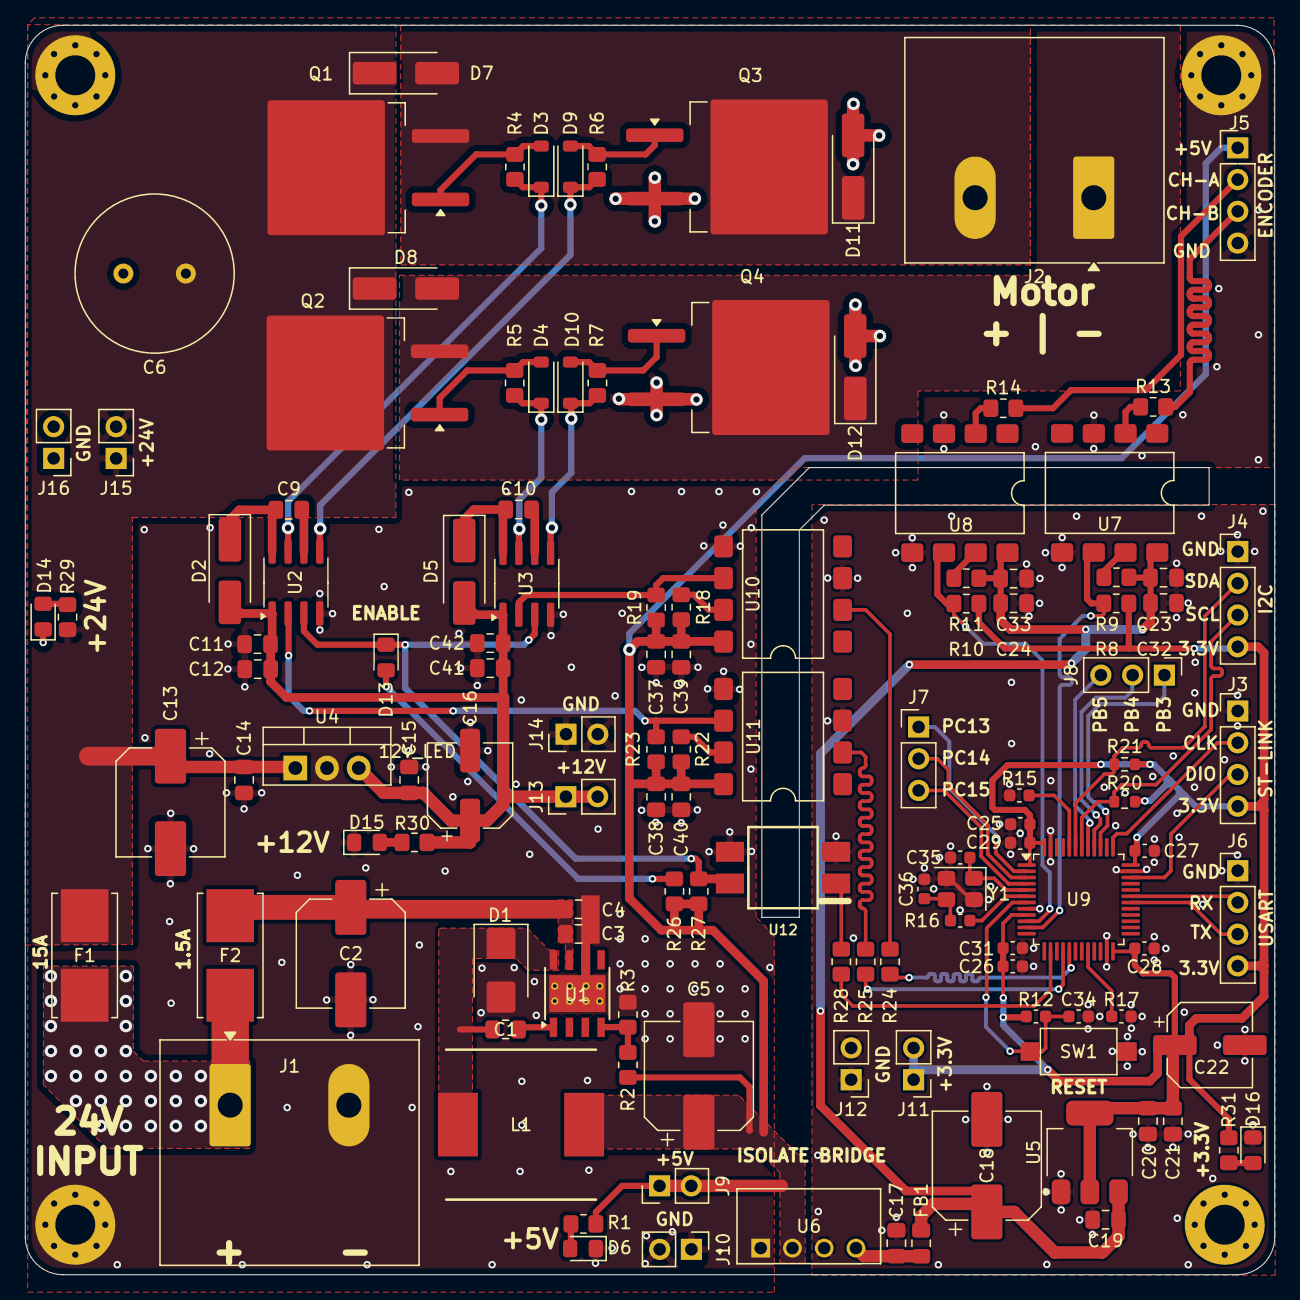
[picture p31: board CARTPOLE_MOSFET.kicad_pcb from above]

Board: 2 copper layers, 100.0 x 100.0 mm, 128 parts (0 on the bottom side), 69 nets.
